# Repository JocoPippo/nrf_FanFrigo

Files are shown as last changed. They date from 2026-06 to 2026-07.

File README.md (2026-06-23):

# Introduzione
In estate il frigo trivalente soffre molto a causa delle alte temperature che non consentono un scambio termico adeguato della serpentina di raffreddamente.
In commercio esistono soluzioni ma queste sono pienamente soddisfacenti.
Così ho deciso di realizzare una soluzione che permetesse di:
- regolare la velocità delle ventole in base alla temperature del vano;
- monitorare e controllare da remoto lo stato della board;
- la seconda ventola, sen non forzata da applicativo, viene attivata quando la prima supera la soglia del 70% di utilizzo così da ridurre la rumorosità;
- non pesare sui consumi elettrici quando non necessario.

La cartella "pheripheral_frigo" contiene il progetto per "Visual studio Code" del firmware della board di gestione delle ventole.
La cartella hardware contiene il progetto in Kicad 9 e i file gerber della scheda di controllo.
"AndroidApp" contiene l'applicativo Android di gestione della board.
Ci si riferisca al file README.md interno a ciascuna cartella per dettagli specifici.

# BOARD
Attualmente la revisione del pcb è la 2.0 in cui è stato aggiunto il supporto per il sensore tachimetrico per ciascuna ventola e la possibilità di valutare la tensione della batteria. Al fine di mantenere i consumi bassi si è scelto di inserire il partitore di tensione sotto il mosfet di controllo della ventola1. Questa scelta, benchè renda più semplice il pcb, complica la parte software che è ancora in fase di sviluppo. Probabilmente verrà sostituta aggiungendo un ulteriore switch.
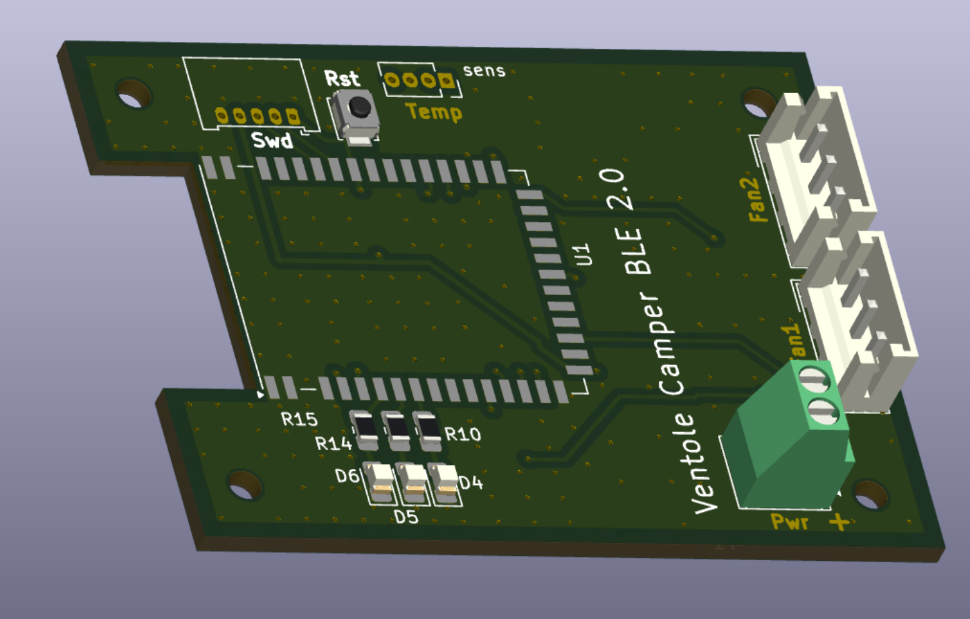
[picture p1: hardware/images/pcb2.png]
Vista lato superiore Front


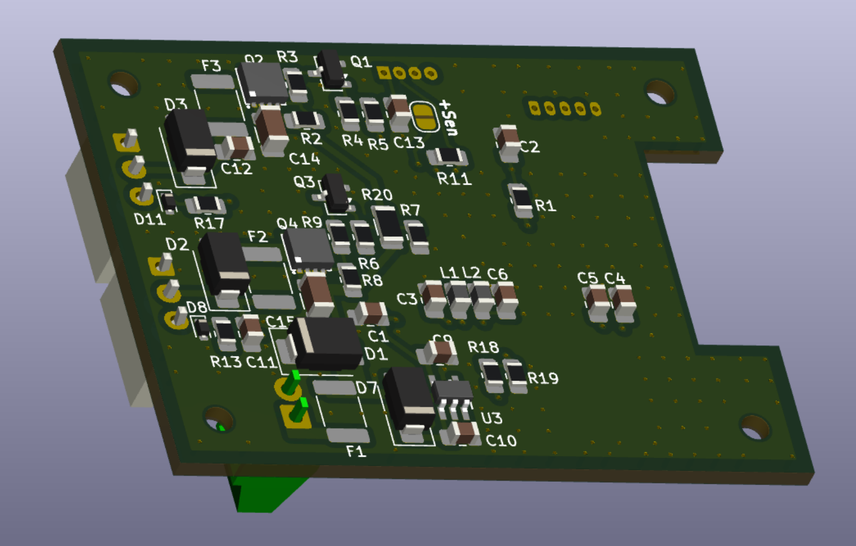
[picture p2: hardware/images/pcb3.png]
Vista lato inferiore BacK


# SOFTWARE GESTIONE
Basato sull'esempio "NRF Blinky" della nordic semiconductor è stato customizzato aggiungendo le funzionalità di riservatezza e di gestione della board.

La [pagina di gestione](AndroidApp/images/app1.png) consente di vedere lo stato corrente ed, eventualmente, di forzarlo. 
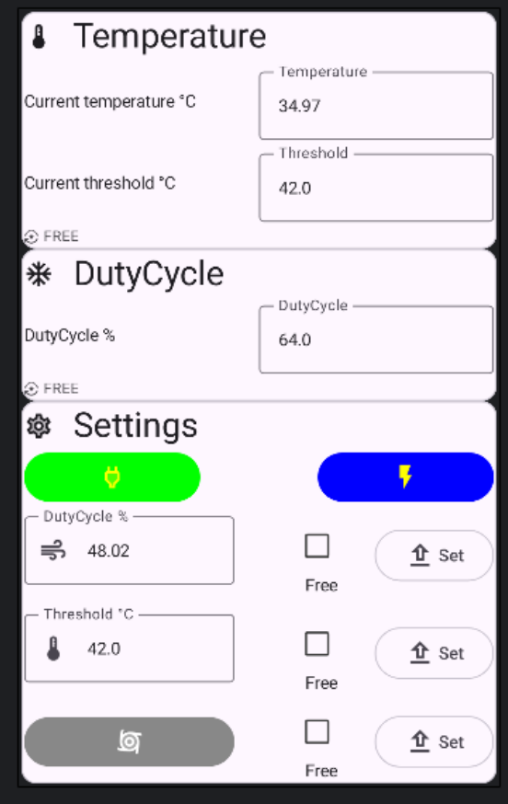
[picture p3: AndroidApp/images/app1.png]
pagina di gestione Board Status


Nella [pagina di settings](AndroidApp/images/App2.png ) si può cambiare la password che avrà valore transitorio fino al nuovo reset della scheda o tramite il ciclo power-off -> power-on o attraverso la pressione del tasto di reset. 
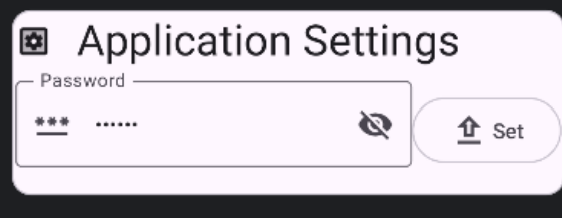
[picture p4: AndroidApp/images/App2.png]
pagina di settings App Settings


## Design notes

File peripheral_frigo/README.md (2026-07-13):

# Introduzione
In estate il frigo trivalente soffre molto a causa delle alte temperature che non consentono un scambio termico adeguato della serpentina di raffreddamente.
In commercio esistono soluzioni ma queste sono pienamente soddisfacenti.
Così ho deciso di realizzare una soluzione che permetesse di:
- regolare la velocità delle ventole in base alla temperature del vano;
- monitorare e controllare da remoto lo stato della board;
- la seconda ventola, sen non forzata da applicativo, viene attivata quando la prima supera la soglia del 70% di utilizzo così da ridurre la rumorosità;
- non pesare sui consumi elettrici quando non necessario.

La definizione dell'hardware la potete trovare qui: [hardware](../hardware/Ventole_Nrf52/). Utilizza una board custom, un sensore di temperatura DS18B20 e due ventole da 120x120mm (ma possono essere sostituite in base alla dimensione dello spazio utile a vostra disposizione).

L'applicazione di gestione su android la potete trovare qui: [AndroidApp](../AndroidApp/README.md). Basata sulla demo [Nrf BLINKY](https://github.com/nordicsemi/Android-nRF-Blinky) della nordic semiconductor è stata customizzata per il controllo e gestione della board custom. 

# Dettagli
Il firmware per la [board](https://github.com/JocoPippo/nrf_FanFrigo) si basa sul modulo [E73-2G4M04S1B](https://www.cdebyte.com/products/E73-2G4M04S1B/2) che utilizza il chip nfr52832 della nordic semiconductor, un ultra low power BLE soc che consente di controllare le ventole da remoto e, se in stand by mode consuma solo 3.5uA e circa 70uA in normal mode senza attivazione delle ventole.
Il che non rappresenta un problema per la batteria nei periodi di fermo prolungato del nostro mezzo.

# Setup
Il codice è scritto seguendo le linee guida del produttore qui troverete la descrizione per il [setup ambiente](https://academy.nordicsemi.com/courses/nrf-connect-sdk-fundamentals/lessons/lesson-1-nrf-connect-sdk-introduction/topic/exercise-1-1/). 
Allo stato della scrittura del codice le versioni dell'SDK e della toolchain è: 3.3.0.

Una volta importato il progetto dentro Visual Studio Code è necessario creare la configurazione di build selezionando "+Add build configuration" nella sezione "APPLICATIONS" di "NRF CONNECT".
- Nella sezione "Board Target" selezionare "Nordic SoC" e scegliere "ebyte_e73_tbb/nrf53832".
- Nella sezione "Base Devicetree Overlays" selezionare "boards/ebyte_e73_tbab_nrf52832.overlay"
- Nella sezione "Extra Devicetree Overlays" selezionare "arduino_serial.overlay"
A questo punto è possibile customizzare altre impostazione per uso specifico per il debugging o altro. Infine cliccare sul bottone "Generate and Build" per creare generare tutti le dipendenze e creare il file da flashare.

# Considerazioni
Attualmente il bluethooth è configurato con cifratura e password fissa definita nel codice, questo è stato necessario poichè non è presito alcun dispositivo di output per stampare la password di sessione.

L'appicativo di gestione consente il cambio dei parametri tra cui la temperatura di soglia e la password, che attualmente durano solo filno al ciclo di disconnessione dell'alimentazione. 
E' prevista la possibilità di salvare le impostazioni di sessione alliinterno della flash ma per il momento è stata commentata perchè salvare la password in modo definitivo avrebbe richiesto il re-flash in caso la si debba resettare.

# Sviluppi futuri 
Assieme alla prossima revisione hardware verranno aggiunte:
- la possibilità di monitorare la velocità delle ventole al fine di essere confidenti che non ci sia un impedimento meccanico alla rotazione;
- il monitoraggio della tesione della battaria durante l'azionamento della ventola principale.

# Creazione build per DFU/FOTA
Per poter eseguire l'aggiornamento via BLE NRF mette a disposizione un sistema automatico per creare il bootloader e integrare nell'applicativo la parte di gestione e scrittura del firmware. E' necessario creare una build che contenga il bootloader e le immagini per i due slot. 
Per rendere il sistema più sicuro è necessario generare una chiave per la firma che nel notro caso si dovrà chiamere _fan_private_2048.pem_ in quanto il makefile è configurato per questo nome file.
Di seguito i comandi da eseguire all'interno di un __"nRF terminal"__ (plugin "NRF CONNECT" -> sezione WELCOME -> Open terminal) per creare la prima immagine da flashare direttamente e il pacchetto __dfu_application.zip__ che contiene il firmware per l'aggiornamento.

### la generazione della chiave di cifratura
_openssl genrsa -out fan_private_2048.pem 2048_

### la build
entrare nella cartella del progetto _peripheral_frigo_ (cd <prj_path>/nrf_FanFrigo/peripheral_frigo)

_west build [-p] -b ebyte_e73_tbb/nrf52832 -- -DSB_CONFIG_BOOTLOADER_MCUBOOT=y ~~-DSB_CONFIG_MCUBOOT_MODE_DIRECT_XIP=y~~ -DCONFIG_NCS_SAMPLE_MCUMGR_BT_OTA_DFU=y -DDTC_OVERLAY_FILE=" <prj_path>/nrf_FanFrigo/peripheral_frigo/boards/ebyte_e73_tbab_nrf52832.overlay" -DDTC_EXTRA_OVERLAY_FILE=" <prj_path>/nrf_FanFrigo/peripheral_frigo/arduino_serial.overlay"_

L'opzione [-p] p è da usare per una _"pristine build"_, quindi la prima volta o quando si cambia la configurazione.
La modalità _SB_CONFIG_MCUBOOT_MODE_DIRECT_XIP_ non sembra funzionare correttamente durante l'aggiornamento, per ora è stata rimossa fino a quando non verrà scoprirta la causa.
Il segnaposto <prj_path> deve essere sostituito con il percorsco completo dove è presente il progetto _"nrf_FanFrigo"_

### il flash completo
 _west flash_   

## DFU
Per il caricamento del firmware può essere utilizzata l'applicazione __"nRF Connect"__ o, in alternativa, __"Device Manager"__. Una volta associato il dispositivo basta inviare il file et voilà l'aggiornamento è servito.

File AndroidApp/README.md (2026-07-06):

# INTRODUZIONE
Applicazione basata sull'esempio "nRF BLINKY" di nordic semiconductor è stato customizzato ed ampliato per adattarsi all'esigenza specifica.
Essendo la mia prima applicazione android, scusatemi per la presenza di errori ed alcuni piccoli e bug ma almeno fà ci per cui è destinata: controllare e comandare la board da remoto al fine di avere una gestione più corretta delle ventole e della temperatura.

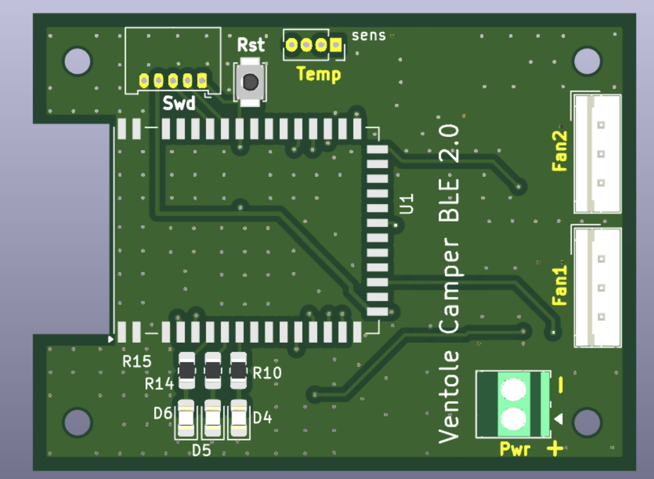
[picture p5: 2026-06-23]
hardware/images/pcb1.png

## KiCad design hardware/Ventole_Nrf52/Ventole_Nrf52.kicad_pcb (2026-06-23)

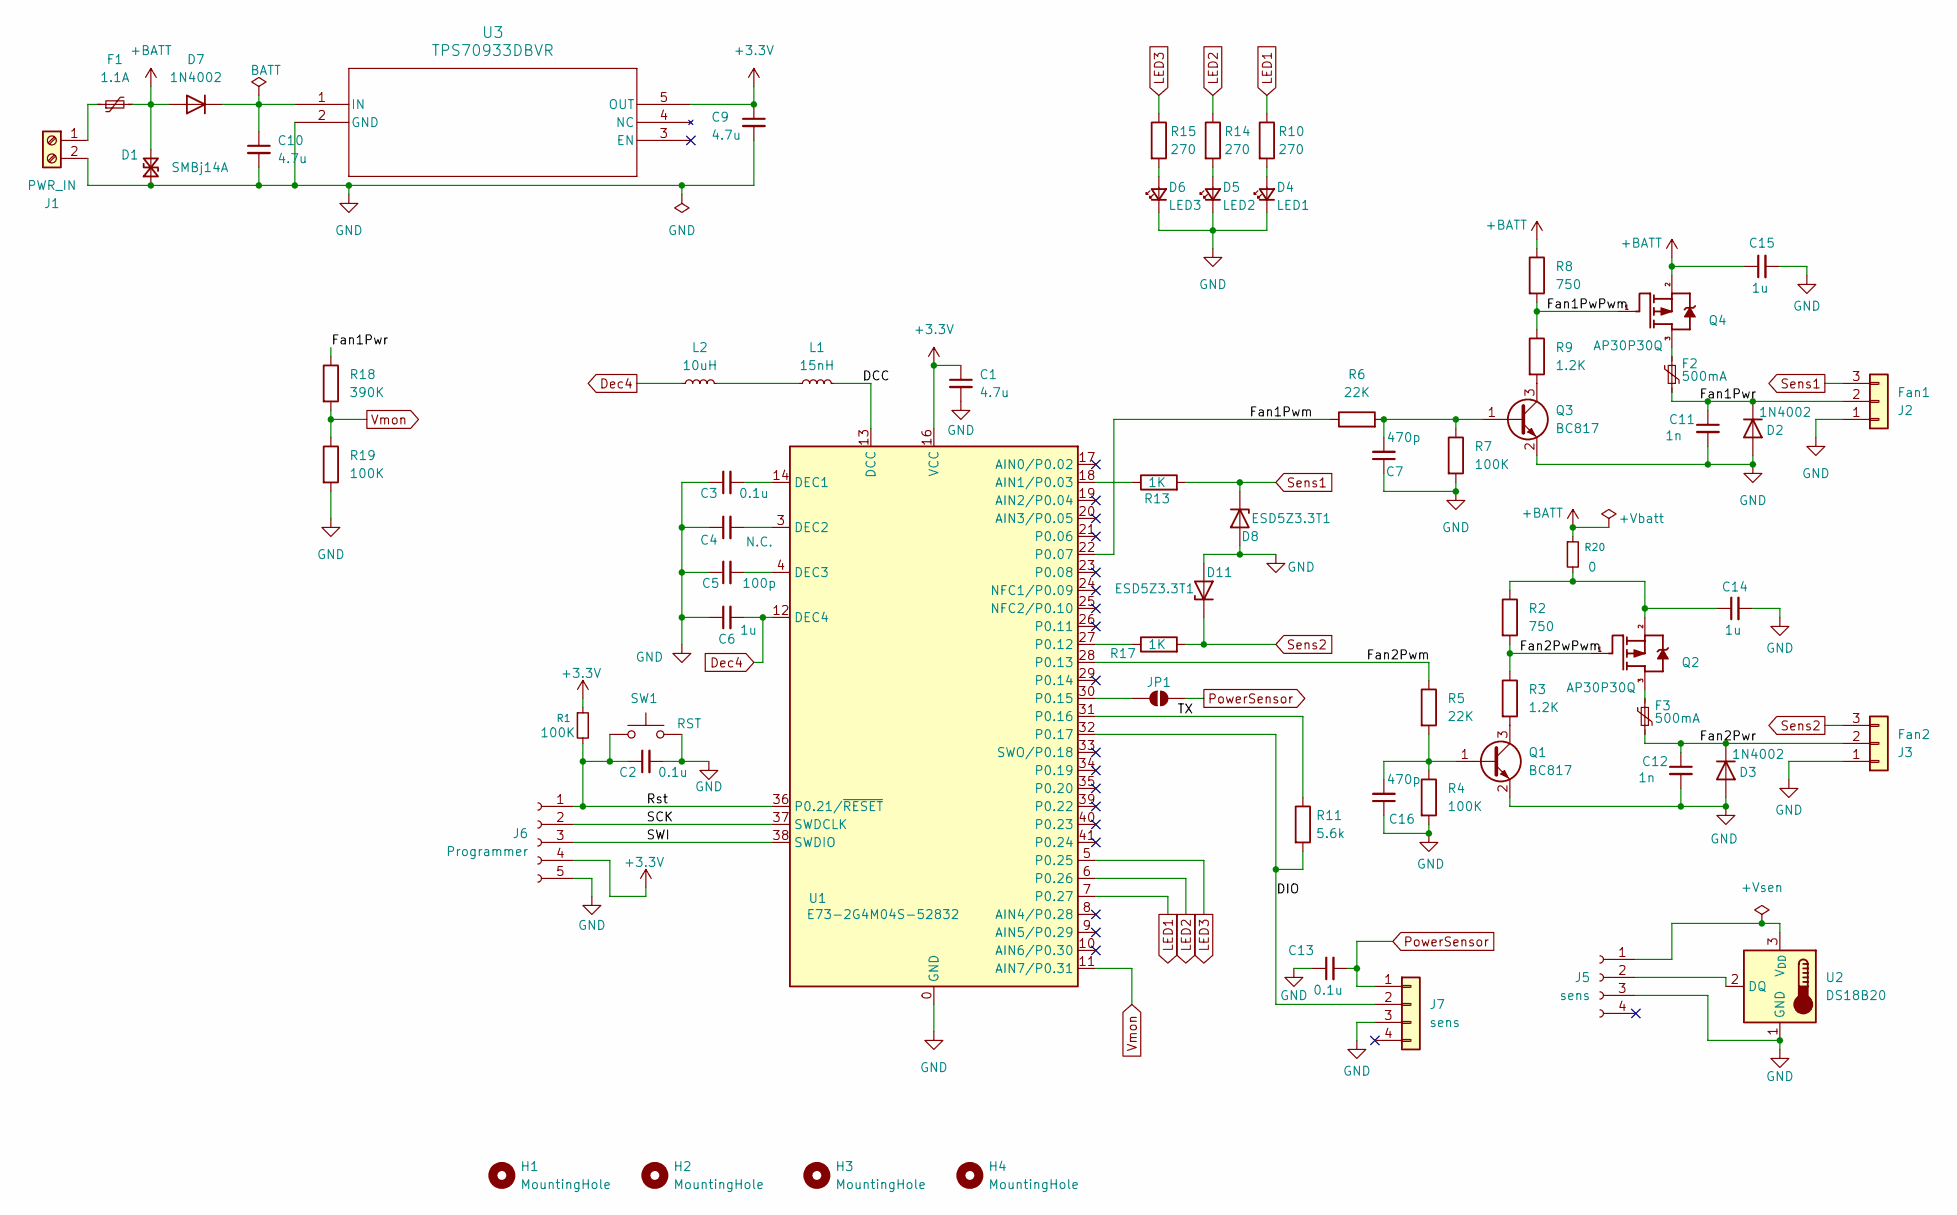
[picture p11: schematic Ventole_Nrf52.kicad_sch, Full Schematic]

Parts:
C1, C9, C10: 4.7u; C_0805_2012Metric_Pad1.18x1.45mm_HandSolder
C2, C3, C13: 0.1u; C_0805_2012Metric_Pad1.18x1.45mm_HandSolder
C4: N.C.; C_0805_2012Metric_Pad1.18x1.45mm_HandSolder
C5: 100p; C_0805_2012Metric_Pad1.18x1.45mm_HandSolder
C6: 1u; C_0805_2012Metric_Pad1.18x1.45mm_HandSolder
C7, C16: 470p; C_1206_3216Metric
C11, C12: 1n; C_0805_2012Metric_Pad1.18x1.45mm_HandSolder
C14, C15: 1u; C_1206_3216Metric
D1: SMBj14A; D_SMB
D2, D3, D7: 1N4002; D_SMA
D4: LED1; LED_0805_2012Metric_Pad1.15x1.40mm_HandSolder
D5: LED2; LED_0805_2012Metric_Pad1.15x1.40mm_HandSolder
D6: LED3; LED_0805_2012Metric_Pad1.15x1.40mm_HandSolder
D8, D11: ESD5Z3.3T1; D_SOD-523
F1: 1.1A; Fuse_1812_4532Metric_Pad1.30x3.40mm_HandSolder
F2, F3: 500mA; Fuse_1812_4532Metric_Pad1.30x3.40mm_HandSolder
H1, H2, H3, H4: MountingHole; MountingHole_2.2mm_M2
J1: PWR_IN; TerminalBlock_MX128-2-2.54_1x02_P2.54mm_Horizontal
J2: Fan1; JST_EH_B3B-EH-A_1x03_P2.50mm_Vertical
J3: Fan2; JST_EH_B3B-EH-A_1x03_P2.50mm_Vertical
J5: sens
J6: Programmer; Molex_PicoBlade_53048-0510_1x05_P1.25mm_Horizontal
J7: sens; PinSocket_1x04_P1.27mm_Vertical
JP1: PowerSensor; SolderJumper-2_P1.3mm_Open_RoundedPad1.0x1.5mm
L1: 15nH; L_0805_2012Metric_Pad1.05x1.20mm_HandSolder
L2: 10uH; L_0805_2012Metric_Pad1.05x1.20mm_HandSolder
Q1, Q3: BC817; SOT-23
Q2, Q4: AP30P30Q; DFN-8_3.0x3.0-E0.65_mos
R1, R4, R7, R19: 100K; R_0805_2012Metric_Pad1.20x1.40mm_HandSolder
R2, R8: 750; R_0805_2012Metric_Pad1.20x1.40mm_HandSolder
R3, R9: 1.2K; R_0805_2012Metric_Pad1.20x1.40mm_HandSolder
R5, R6: 22K; R_0805_2012Metric_Pad1.20x1.40mm_HandSolder
R10, R14, R15: 270; R_0805_2012Metric_Pad1.20x1.40mm_HandSolder
R11: 5.6k; R_0805_2012Metric_Pad1.20x1.40mm_HandSolder
R13, R17: 1K; R_0805_2012Metric_Pad1.20x1.40mm_HandSolder
R18: 390K; R_0805_2012Metric_Pad1.20x1.40mm_HandSolder
R20: 0; R_1206_3216Metric
SW1: RST; SW_SPST_B3U-1000P
U1: E73-2G4M04S-52832; E73-2G4M04S
U2: DS18B20; TO-92_Inline
U3: TPS70933DBVR; DBV5_TEX-M

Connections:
+3.3V: C1.1, C9.1, J6.4, R1.1, U1.16 (VCC), U3.5 (OUT)
+BATT: C15.1, D1.2 (A2), D7.2 (A), F1.2, Q4.2 (S), R8.1, R20.1
/DCC: L1.2, U1.13 (DCC)
/DIO: J7.2, R11.2, U1.32 (P0.17)
/Fan1PwPwm: Q4.1 (G), R8.2, R9.1
/Fan1Pwm: R6.1, U1.22 (P0.07)
/Fan1Pwr: C11.1, D2.1 (K), F2.1, J2.2, R18.1
/Fan2PwPwm: Q2.1 (G), R2.2, R3.1
/Fan2Pwm: R5.1, U1.28 (P0.13)
/Fan2Pwr: C12.1, D3.1 (K), F3.1, J3.2
/Rst: C2.1, J6.1, R1.2, SW1.1, U1.36 (P0.21/~RESET)
/SCK: J6.2, U1.37 (SWDCLK)
/SWI: J6.3, U1.38 (SWDIO)
/TX: R11.1, U1.31 (P0.16)
Dec4: C6.2, L2.1, U1.12 (DEC4)
GND: C1.2, C2.2, C3.1, C4.1, C5.1, C6.1, C7.1, C9.2, C10.2, C11.2, C12.2, C13.1, C14.2, C15.2, C16.1, D1.1 (A1), D2.2 (A), D3.2 (A), D4.1 (K), D5.1 (K), D6.1 (K), D8.2 (A), D11.2 (A), J1.2, J2.1, J3.1, J5.3, J6.5, J7.3, Q1.2 (E), Q3.2 (E), R4.2, R7.2, R19.2, SW1.2, U1.0 (GND), U1.1 (GND), U1.2 (GND), U1.15 (GND), U1.42 (GND), U1.43 (GND), U2.1 (GND), U3.2 (GND)
LED1: R10.1, U1.7 (P0.27)
LED2: R14.1, U1.6 (P0.26)
LED3: R15.1, U1.5 (P0.25)
unnamed: D4.2 (A), R10.2
unnamed: D5.2 (A), R14.2
unnamed: D6.2 (A), R15.2
unnamed: C10.1, D7.1 (K), U3.1 (IN)
unnamed: F1.1, J1.1
unnamed: J5.1, U2.3 (V_{DD})
unnamed: J5.2, U2.2 (DQ)
unnamed: JP1.1 (A), U1.30 (P0.15)
unnamed: L1.1, L2.2
unnamed: C16.2, Q1.1 (B), R4.1, R5.2
unnamed: Q1.3 (C), R3.2
unnamed: F3.2, Q2.3 (D)
unnamed: C14.1, Q2.2 (S), R2.1, R20.2
unnamed: C7.2, Q3.1 (B), R6.2, R7.1
unnamed: Q3.3 (C), R9.2
unnamed: F2.2, Q4.3 (D)
unnamed: R13.1, U1.18 (AIN1/P0.03)
unnamed: C3.2, U1.14 (DEC1)
unnamed: C4.2, U1.3 (DEC2)
unnamed: C5.2, U1.4 (DEC3)
unnamed: R17.1, U1.27 (P0.12)
PowerSensor: C13.2, J7.1, JP1.2 (B)
Sens1: D8.1 (K), J2.3, R13.2
Sens2: D11.1 (K), J3.3, R17.2
Vmon: R18.2, R19.1, U1.11 (AIN7/P0.31)

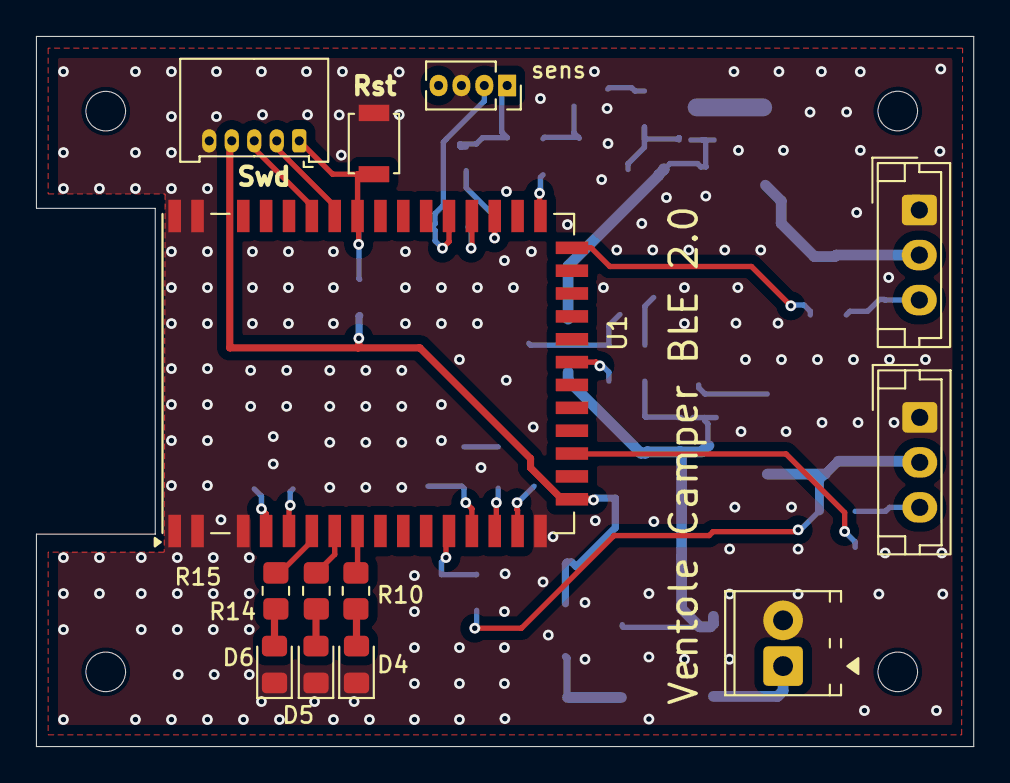
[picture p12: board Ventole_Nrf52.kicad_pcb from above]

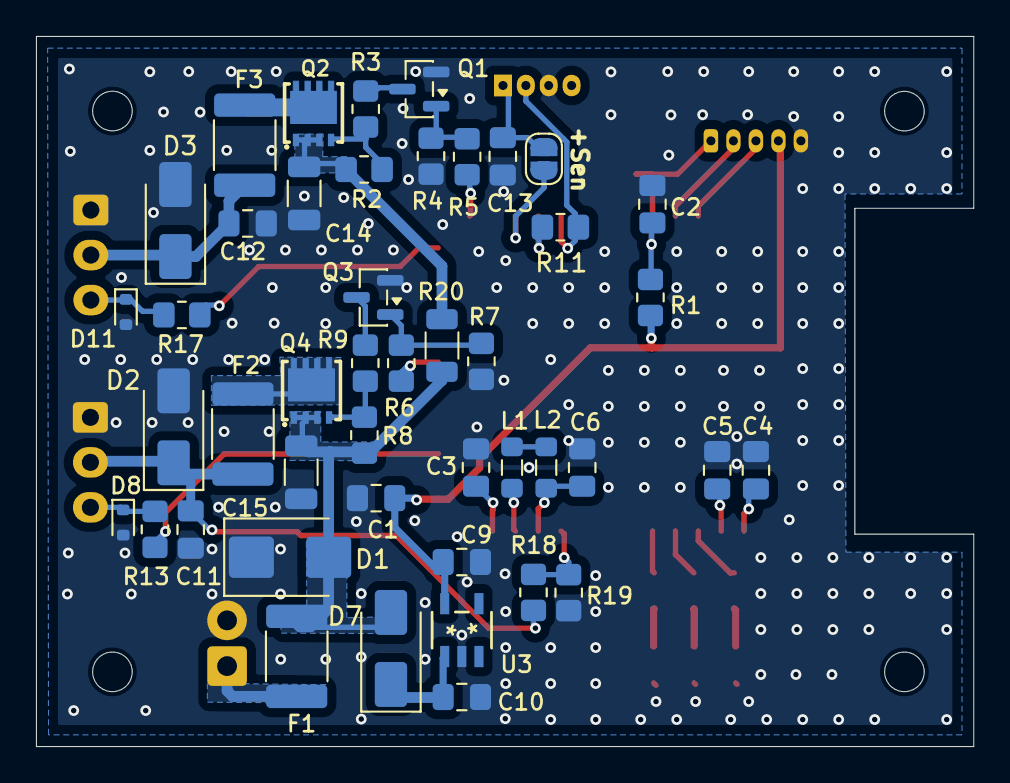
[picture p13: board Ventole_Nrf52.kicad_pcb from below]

Board: 2 copper layers, 52.1 x 39.5 mm, 62 parts (45 on the bottom side), 42 nets.

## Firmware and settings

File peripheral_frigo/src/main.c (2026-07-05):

/*
 * Copyright (c) 2023 Nordic Semiconductor ASA
 *
 * SPDX-License-Identifier: LicenseRef-Nordic-5-Clause
 */

#include <zephyr/kernel.h>
#include <zephyr/logging/log.h>
#include <zephyr/bluetooth/gap.h>
#include <zephyr/bluetooth/uuid.h>
#include <zephyr/bluetooth/conn.h>
#include <zephyr/posix/netinet/in.h>
#include <zephyr/drivers/gpio.h>
#include <zephyr/drivers/sensor.h>
#include <zephyr/drivers/pwm.h>
#include <zephyr/bluetooth/bluetooth.h>
#include <zephyr/pm/device.h>

#include <zephyr/net/net_ip.h>
#include <zephyr/posix/arpa/inet.h>

#include <zephyr/bluetooth/hci_vs.h>
#include <zephyr/settings/settings.h>

//#include <zephyr/settings/settings.h> // for bonding and flash access
#include "my_fbs.h"

LOG_MODULE_REGISTER(Fan_Frigo_Camper, 1);

#define DEVICE_NAME CONFIG_BT_DEVICE_NAME
#define DEVICE_NAME_LEN (sizeof(DEVICE_NAME) - 1)

#define RUN_STATUS_LED DK_LED1
#define CON_STATUS_LED DK_LED2

#define STACKSIZE 1024
#define PRIORITY 7

#define RUN_LED_BLINK_INTERVAL 2000

#define MAX_PULSE_NS 50000
#define MAX_PULSE_2FAN2 30000
//#define MAX_PULSE_2FAN2 20000
#define MIN_PULSE_WIDTH	7500
//#define MIN_PULSE_WIDTH	250

#define GETMASK(size)  ((1ULL<<(((size)*8)-1))-1)

#define INT2FLOAT_BITS 16
#define HI_INT2FLOAT_MASK  0xFFFF0000U
#define LOW_INT2FLOAT_MASK 0x0000FFFFU

#define MAX_TEMPERATURE 80U

#define STORAGE_SETTINGS_ROOT "up"
#define STORAGE_SETTINGS_KEY  "key"
#define STORAGE_SETTINGS_TEMP  "temp"


struct stateAndValueU32 {
 uint32_t value;
 bool forced;
};

struct stateAndValueBool {
 bool value;
 bool forced;
};

static int fan_settings_set(const char *name, size_t len,
                            settings_read_cb read_cb, void *cb_arg);
static int fan_settings_export(int (*storage_func)(const char *name, const void *value, size_t val_len));
struct settings_handler fan_conf = {
    .name = STORAGE_SETTINGS_ROOT,
    .h_set = fan_settings_set,
    .h_export = fan_settings_export
};

/* Define the data you want to stream over Bluetooth LE */
// stores the used dutycycle 
static uint32_t local_dutycycle_value = 0;
// stores the remote required dutycycle
static struct stateAndValueU32 app_dutycycle = {0,false};
static bool local_fan2State = false;
static struct stateAndValueBool app_fan2State = {false,false};
static bool app_poweron_state = true;
static uint32_t app_temperature_value = 10<<INT2FLOAT_BITS;
static struct stateAndValueU32 app_threshold ={32<<INT2FLOAT_BITS, false};// = 42<<INT2FLOAT_BITS;
static bool app_leds_state = true;
static bool connection_state = false;
static bool pwmOff = false;
static uint32_t dutyPulse;


static const struct gpio_dt_spec fanGpio_spec = GPIO_DT_SPEC_GET(DT_ALIAS(fan2), gpios);
static const struct gpio_dt_spec powerGpio_spec = GPIO_DT_SPEC_GET(DT_ALIAS(poweron), gpios);
static const struct pwm_dt_spec pwm_fan1 = PWM_DT_SPEC_GET(DT_NODELABEL(fanpwm1));
static const struct pwm_dt_spec pwm_fan2 = PWM_DT_SPEC_GET(DT_NODELABEL(fanpwm2));


static const struct gpio_dt_spec led0_spec = GPIO_DT_SPEC_GET(DT_ALIAS(led0), gpios);
static const struct gpio_dt_spec led1_spec = GPIO_DT_SPEC_GET(DT_ALIAS(led1), gpios);
static const struct gpio_dt_spec led2_spec = GPIO_DT_SPEC_GET(DT_NODELABEL(led2), gpios);

static const struct  device *uart_dev = DEVICE_DT_GET(DT_NODELABEL(uart0));

static const struct gpio_dt_spec btn0_spec = GPIO_DT_SPEC_GET(DT_NODELABEL(button0), gpios);
static const struct gpio_dt_spec btn1_spec = GPIO_DT_SPEC_GET(DT_NODELABEL(button1), gpios);

static const struct bt_data ad[] = {
	BT_DATA_BYTES(BT_DATA_FLAGS, (BT_LE_AD_GENERAL | BT_LE_AD_NO_BREDR)),
	BT_DATA(BT_DATA_NAME_COMPLETE, DEVICE_NAME, DEVICE_NAME_LEN),

};

static const struct bt_le_adv_param *adv_param = BT_LE_ADV_PARAM(
	(BT_LE_ADV_OPT_CONN | BT_LE_ADV_OPT_USE_IDENTITY), /* Connectable advertising and use identity address */
	3400, /* Min Advertising Interval 3000ms (4800*0.625ms) */
	4200, /* Max Advertising Interval 3375ms (5400*0.625ms) */
	NULL); /* Set to NULL for undirected advertising */

static struct k_work adv_work;


static const struct bt_data sd[] = {
	BT_DATA_BYTES(BT_DATA_UUID128_ALL, BT_UUID_FBS_VAL),
};

struct k_sem dutycycle_sem;
bool dutyToBeUpdate = false;

// for FAN2 managements
bool fan2ToBeUpdate = false;
static bool fan2ToBeStarted;

const struct device *tempDev;
unsigned int passkey = 123456;

float getFloatTemp4Int(uint32_t T_Arg);
static void app_setLeds_cb(bool ledState);

static void advertising_start(void)
{
	k_work_submit(&adv_work);
}

static void adv_work_handler(struct k_work *work)
{
	int err = bt_le_adv_start(adv_param, ad, ARRAY_SIZE(ad), sd, ARRAY_SIZE(sd));

	if (err) {
		LOG_DBG("Advertising failed to start (err %d)\n", err);
		return;
	}

	LOG_DBG("Advertising successfully started\n");
}

static void display_passkey(struct bt_conn *conn, unsigned int passkey)
{
	char peer_addr[BT_ADDR_LE_STR_LEN];
	bt_addr_le_to_str(bt_conn_get_dst(conn), peer_addr, sizeof(peer_addr));

	LOG_INF("Enter passkey on %s: %06u", peer_addr, passkey);
}

static void cancel_authentication(struct bt_conn *conn)
{
	char peer_addr[BT_ADDR_LE_STR_LEN];
	bt_addr_le_to_str(bt_conn_get_dst(conn), peer_addr, sizeof(peer_addr));

	LOG_INF("Pairing canceled by remote: %s", peer_addr);
}

/*
 * Get a device structure from a devicetree node with compatible
 * "maxim,ds18b20". (If there are multiple, just pick one.)
 */

static const struct device *get_ds18b20_device(void)
{
	const struct device *const dev = DEVICE_DT_GET_ANY(maxim_ds18b20);

	if (dev == NULL) {
		// No such node, or the node does not have status "okay". //
		LOG_DBG("\nError: no device found.\n");
		return NULL;
	}

	if (!device_is_ready(dev)) {
		LOG_DBG("\nError: Device \"%s\" is not ready; "
		       "check the driver initialization logs for errors.\n",
		       dev->name);
		return NULL;
	}

	LOG_DBG("Found device \"%s\", getting sensor data\n", dev->name);
	return dev;
}

/*
static void pairing_confirm(struct bt_conn *conn)
{
	char addr[BT_ADDR_LE_STR_LEN];

	bt_addr_le_to_str(bt_conn_get_dst(conn), addr, sizeof(addr));

	bt_conn_auth_pairing_confirm(conn);

	LOG_DBG("Pairing confirmed: %s\n", addr);
}

static void pairing_complete(struct bt_conn *conn, bool bonded)
{
	char addr[BT_ADDR_LE_STR_LEN];

	bt_addr_le_to_str(bt_conn_get_dst(conn), addr, sizeof(addr));

	LOG_DBG("Pairing completed: %s, bonded: %d\n", addr, bonded);
}

static void pairing_failed(struct bt_conn *conn, enum bt_security_err reason)
{
	char addr[BT_ADDR_LE_STR_LEN];

	bt_addr_le_to_str(bt_conn_get_dst(conn), addr, sizeof(addr));

	LOG_DBG("Pairing failed conn: %s, reason %d\n", addr, reason);
}
*/

static uint32_t uintFromFloat(float data) {
	uint32_t result;

	result = (uint32_t) data;
	data -= result;
	result <<= INT2FLOAT_BITS;
	return result | (int32_t)(data *100.f);
}

static uint32_t pulse2Uint(uint32_t pulse) {

	uint32_t result;
	float tmp;
	tmp = ((float)pulse/(float)MAX_PULSE_NS)* 100.0f;
	result = uintFromFloat(tmp);
	return result;
}

static uint32_t percentage2Uint(uint32_t percentage) {

	uint32_t result;
	float tmp = getFloatTemp4Int(percentage); // percentage in float rappresentation
	if(tmp > ((float)MAX_PULSE_2FAN2/((float)MAX_PULSE_NS)*100.0f))
		tmp *=2;	
	result = (tmp * (float)MAX_PULSE_NS/100.0f);
	return result;
}


static void recycled_cb(void)
{
	LOG_DBG("Connection object available from previous conn. Disconnect is complete!\n");
	advertising_start();
}

static uint32_t app_getDutyCycle_cb(void)
{
	uint32_t result;
	if(app_dutycycle.forced) {
		result = pulse2Uint(app_dutycycle.value);
		result |= app_dutycycle.forced<<(sizeof(app_dutycycle.value)*8-1);
	}
	else {
		result = pulse2Uint(local_dutycycle_value);
	}
	return result;
}

static uint8_t app_getFan2_cb(void)
{
	if(app_fan2State.forced)
		return app_fan2State.value | app_fan2State.forced<<(sizeof(app_fan2State.value)*8-1);
	else
		return local_fan2State;

}

static bool app_getPoweron_cb(void)
{
	return app_poweron_state;
}

static int32_t app_getTemperature_cb(void)
{
	return app_temperature_value;
}

static uint32_t app_getThreshold_cb(void)
{
	uint32_t result;
	result = app_threshold.value;
	if(app_threshold.forced) {
		result |= app_threshold.forced<<(sizeof(app_threshold.value)*8-1);
	}
	return result;
}

static bool app_getLeds_cb(void)
{
	return app_leds_state;
}

/**
 * callback used to set the dutycycle value
 * @param dutyCycleValue represents the new value of dutycycle to set
 * 					a negative value indicates the value has to be forced
 * 					a postive value indicates to use the calculated value
 */
static void app_setDutyCycle_cb(uint32_t dutyCycleValue)
{
	dutyCycleValue = htonl(dutyCycleValue); 

	if(dutyCycleValue & 0x80000000U) {
		app_dutycycle.forced = true;
			//LPP due the received value is set as percentage of pulse it must be re-calibrate in 
		// order to obtain the pulse period
		app_dutycycle.value = percentage2Uint(GETMASK(sizeof(app_dutycycle.value)) & dutyCycleValue);
		app_dutycycle.value = app_dutycycle.value>MAX_PULSE_NS?MAX_PULSE_NS:app_dutycycle.value;
		app_dutycycle.value = app_dutycycle.value<MIN_PULSE_WIDTH?0:app_dutycycle.value;

	}
	else {
		app_dutycycle.forced = false;
		app_dutycycle.value = local_dutycycle_value;
/* 		{
			k_sem_take(&dutycycle_sem, K_FOREVER);
			fan2ToBeUpdate=true;
			k_sem_give(&dutycycle_sem);
		} */
	}

	k_sem_take(&dutycycle_sem, K_FOREVER);
	dutyToBeUpdate = true;
	k_sem_give(&dutycycle_sem);
}

/**
 * callback used to set the Fan2 state
 * @param fan2_state indicates if the Fan2 must be set or not
 * 					a negative value indicates the state has to be forced
 * 					a postive value indicates to use the automatic (calculated) state
 */
static void app_setFan2_cb(uint8_t fan2_state)
{
	int size = sizeof(app_fan2State.value);
	//LPP TODO VERIFY HOW HANDLE THE IO in case on not forced -> shall be the stored previous state???
	if(fan2_state & (1<<(size*8-1))) {
		app_fan2State.forced = true;
		fan2_state &= GETMASK(size);
		app_fan2State.value = fan2_state; // evaluate the action
	}
	else {
		app_fan2State.forced = false;
		//status and pwm counter will be set in the next iteration of temperature acquisition
	}

/* 	k_sem_take(&fan_sem, K_FOREVER);
	fan2ToBeUpdate=true;
	k_sem_give(&fan_sem);
 */
	k_sem_take(&dutycycle_sem, K_FOREVER);
	fan2ToBeUpdate=true;
	dutyToBeUpdate = true;
	k_sem_give(&dutycycle_sem);
}


/**
 * The function `set_tx_power` is used to set the transmit power level for a specific Bluetooth handle.
 * 
 * @param handle_type The `handle_type` parameter in the `set_tx_power` function is used to specify the
 * type of handle being used. It is of type `uint8_t` and is passed as an argument to the function. The
 * handle type typically indicates whether the handle refers to a connection handle, advertising handle
 * @param handle The `handle` parameter in the `set_tx_power` function is used to specify the
 * connection handle for which the transmit power level needs to be set. It is of type `uint16_t`,
 * which means it is a 16-bit unsigned integer value. This handle uniquely identifies the connection
 * between the
 * @param tx_pwr_lvl The `tx_pwr_lvl` parameter in the `set_tx_power` function represents the transmit
 * power level that you want to set for a specific Bluetooth device. It is of type `int8_t`, which
 * means it is an 8-bit signed integer representing the power level in decibels (
 * 
 * @return The function `set_tx_power` returns void, which means it does not return any value.
 */
static void set_tx_power(uint8_t handle_type, uint16_t handle, int8_t tx_pwr_lvl)
{
	struct bt_hci_cp_vs_write_tx_power_level *cp;
	struct bt_hci_rp_vs_write_tx_power_level *rp;
	struct net_buf *buf, *rsp = NULL;
	int err;
	buf = bt_hci_cmd_alloc(K_TIMEOUT_ABS_MS(1)); 
	//buf = bt_hci_cmd_create(BT_HCI_OP_VS_WRITE_TX_POWER_LEVEL,
	//			sizeof(*cp));
	if (!buf) {
		printk("Unable to allocate command buffer\n");
		return;
	}

	cp = net_buf_add(buf, sizeof(*cp));
	cp->handle = sys_cpu_to_le16(handle);
	cp->handle_type = handle_type;
	cp->tx_power_level = tx_pwr_lvl;

	err = bt_hci_cmd_send_sync(BT_HCI_OP_VS_WRITE_TX_POWER_LEVEL,
				   buf, &rsp);
	if (err) {
		uint8_t reason = rsp ?
			((struct bt_hci_rp_vs_write_tx_power_level *)
			  rsp->data)->status : 0;
		printk("Set Tx power err: %d reason 0x%02x\n", err, reason);
		return;
	}

	rp = (void *)rsp->data;

	net_buf_unref(rsp);
}

/**
 * set Uart power state
 */
static void setUartPowerOnState(bool enabled) {
	int rc;
	if(!enabled) {
		rc = pm_device_action_run(uart_dev , PM_DEVICE_ACTION_SUSPEND);
		if (rc < 0) {
			LOG_ERR("Could not suspend uart0 (%d)\n" , rc);
		}
	}
	else {
		rc = pm_device_action_run(uart_dev , PM_DEVICE_ACTION_RESUME);
		if (rc < 0) {
			LOG_ERR("Could not resume uart0 (%d)\n" , rc);
		}
	}
}

/**
 * set leds and PWM power state
 */
static void setDeviceEnableState(bool enabled) {
	int rc;
	if(!enabled) {
		// turn off leds
		bool prevLedState = app_leds_state;
		app_setLeds_cb(false);
		app_leds_state = prevLedState;

		rc = pm_device_action_run(pwm_fan1.dev , PM_DEVICE_ACTION_SUSPEND);
		if (rc < 0) {
			LOG_ERR("Could not suspend fan1 (%d)\n" , rc);
		}
		rc = pm_device_action_run(pwm_fan2.dev , PM_DEVICE_ACTION_SUSPEND);
		if (rc < 0) {
			LOG_ERR("Could not suspend fan2 (%d)\n" , rc);
		}

	}
	else {
		//turn on leds
		if(app_leds_state)
			app_setLeds_cb(true);

		rc = pm_device_action_run(pwm_fan1.dev , PM_DEVICE_ACTION_RESUME);
		if (rc < 0) {
			LOG_ERR("Could not resume fan1 (%d)\n" , rc);
		}
		rc = pm_device_action_run(pwm_fan2.dev , PM_DEVICE_ACTION_RESUME);
		if (rc < 0) {
			LOG_ERR("Could not resume fan2 (%d)\n" , rc);
		}
		if(pwm_set_pulse_dt(&pwm_fan1, 0) !=0 ) {
    		LOG_ERR("Error: setting 0 pulse to device %s", pwm_fan1.dev->name);
		}
		if(pwm_set_pulse_dt(&pwm_fan2, 0) !=0 ) {
    		LOG_ERR("Error: setting 0 pulse to device %s", pwm_fan2.dev->name);
		}
	}
}



static void app_setPoweron_cb(bool poweron) {
 
	if (app_poweron_state && !poweron) {
		setUartPowerOnState(false);
		setDeviceEnableState(false);
		pwmOff = true;
	}
	if (!app_poweron_state && poweron) {
		setUartPowerOnState(true);
		setDeviceEnableState(true);
		// to avoid restart fan to maximum when powered off and on
		k_sem_take(&dutycycle_sem, K_NO_WAIT);
		//to upadate the dutycycle value
		dutyToBeUpdate = true;
		//and force the change 
		fan2ToBeUpdate=true;
		k_sem_give(&dutycycle_sem);		
		pwmOff = false;
	}
	app_poweron_state = poweron; // evaluate the action
}

static void app_setThreshold_cb(uint32_t thresholdValue)
{	
	thresholdValue = htonl(thresholdValue); 
	
	if(thresholdValue & 0x80000000U) {
		app_threshold.forced = true;
		app_threshold.value = GETMASK(sizeof(app_threshold.value)) & thresholdValue;
		uint32_t maxTmp= (MAX_TEMPERATURE << INT2FLOAT_BITS);
		app_threshold.value = app_threshold.value>maxTmp?maxTmp:app_threshold.value;
	}
	else {
		app_threshold.forced = false;
	}
}


static void app_setLeds_cb(bool ledState) {
int rc;
	if (app_leds_state && !ledState) {
		gpio_pin_configure_dt(&led0_spec , GPIO_INPUT | GPIO_PULL_DOWN);
		gpio_pin_configure_dt(&led1_spec , GPIO_INPUT | GPIO_PULL_DOWN);
		rc = pm_device_action_run(led0_spec.port , PM_DEVICE_ACTION_SUSPEND);
		if (rc < 0) { 
			LOG_ERR("Could not suspend led0 (%d)\n" , rc);
		}
		rc = pm_device_action_run(led1_spec.port , PM_DEVICE_ACTION_SUSPEND);
		if (rc < 0) {
			LOG_ERR("Could not suspend led1 (%d)\n" , rc);
		} 
	}
	if (!app_leds_state && ledState) {
 		rc = pm_device_action_run(led0_spec.port , PM_DEVICE_ACTION_RESUME);
		if (rc < 0) {
			LOG_ERR("Could not resume led0 (%d)\n" , rc);
		}
		rc = pm_device_action_run(led1_spec.port , PM_DEVICE_ACTION_RESUME);
		if (rc < 0) {
			LOG_ERR("Could not resume led1 (%d)\n" , rc);
		} 
		gpio_pin_configure_dt(&led0_spec , GPIO_OUTPUT_LOW);
		gpio_pin_configure_dt(&led1_spec , GPIO_OUTPUT_LOW);
		//if connected then lights up the led
		gpio_pin_set_dt(&led1_spec, connection_state);
	}

	app_leds_state = ledState; // evaluate the action
}


static void app_setPsw_cb(uint32_t pswValue)
{
	pswValue = htonl(pswValue); 

	passkey = pswValue;
	bt_passkey_set(passkey);
	//LPP TODO TODO
	//execute a disconnetion in order to use the new password
}

/* STEP 18.1 - Define the thread function  */
/*
void send_data_thread(void)
{
	while (1) {
		// Simulate data //
		simulate_data();
		// Send notification, the function sends notifications only if a client is subscribed //
		my_fbs_send_temperature_notify(app_temperature_value);
		k_sleep(K_MSEC(NOTIFY_INTERVAL));
	}
}
*/

/* STEP 18.1 - Define the thread function  */
/*
void send_duty_thread(void)
{
	while (1) {
		// Simulate data //
		simulate_dutycycle();
		// Send notification, the function sends notifications only if a client is subscribed //
		my_fbs_send_dutycycle_notify(app_dutycycle_value);
		k_sleep(K_MSEC(NOTIFY_INTERVAL));
	}
}
*/

static int init_pwm(void) {

	if (!pwm_is_ready_dt(&pwm_fan1)) {
    	LOG_ERR("Error: PWM device %s is not ready", pwm_fan1.dev->name);
    	return -1;
	}

	if (!pwm_is_ready_dt(&pwm_fan2)) {
    	LOG_ERR("Error: PWM device %s is not ready", pwm_fan2.dev->name);
    	return -1;
	}
	if(pwm_set_pulse_dt(&pwm_fan1, 0) !=0 ) {
    	LOG_ERR("Error: setting 0 pulse to device %s", pwm_fan1.dev->name);
    	return -1;
	}
	if(pwm_set_pulse_dt(&pwm_fan2, 0) !=0 ) {
    	LOG_ERR("Error: setting 0 pulse to device %s", pwm_fan2.dev->name);
    	return -1;
	}
	return 0;
}

static void on_connected(struct bt_conn *conn, uint8_t err)
{
	if (err) {
		LOG_DBG("Connection failed (err %u)\n", err);
		return;
	}

	LOG_DBG("Connected\n");
	gpio_pin_set_dt(&led1_spec, 1);
	connection_state=true;
}
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
int main(void)
{
	int blink_status = 0;
	int err;
	k_sem_init(&dutycycle_sem, 1, 1);

	LOG_INF("Starting acquiring temp sensor \n");
	tempDev = get_ds18b20_device();
	
	if (tempDev == NULL) {
		return 0;
	}
	
	gpio_pin_configure_dt(&led0_spec, GPIO_OUTPUT);
	gpio_pin_configure_dt(&led1_spec, GPIO_OUTPUT);
	gpio_pin_configure_dt(&led2_spec, GPIO_OUTPUT);
	gpio_pin_set_dt(&led0_spec, 0);
	gpio_pin_set_dt(&led1_spec, 0);
	gpio_pin_set_dt(&led2_spec, 0);

	
	err = init_pwm();
	if (err) {
		LOG_ERR("PWM init failed (err %d)\n", err);
		return -1;
	}
	
	err = bt_enable(NULL);
	if (err) {
		LOG_ERR("Bluetooth init failed (err %d)\n", err);
		return -1;
	}
	//UNUSED so configure as input to reduce power
	gpio_pin_configure_dt(&btn0_spec, GPIO_INPUT | GPIO_PULL_DOWN);
	gpio_pin_configure_dt(&btn1_spec, GPIO_INPUT | GPIO_PULL_DOWN);
	err = pm_device_action_run(btn0_spec.port, PM_DEVICE_ACTION_SUSPEND);
	if (err < 0) {
			LOG_ERR("Could not suspend button0 (%d)\n", err);
	}
	err = pm_device_action_run(btn1_spec.port, PM_DEVICE_ACTION_SUSPEND);
	if (err < 0) {
			LOG_ERR("Could not suspend button1 (%d)\n", err);
	}
	gpio_pin_configure_dt(&led2_spec, GPIO_INPUT | GPIO_PULL_DOWN);
	err = pm_device_action_run(led2_spec.port, PM_DEVICE_ACTION_SUSPEND);
	if (err < 0) {
			LOG_ERR("Could not suspend led2 (%d)\n", err);
	}
	// no more used
	gpio_pin_configure_dt(&fanGpio_spec , GPIO_INPUT | GPIO_PULL_DOWN);
	err = pm_device_action_run(fanGpio_spec.port, PM_DEVICE_ACTION_SUSPEND);
	if (err < 0) {
			LOG_ERR("Could not suspend fanGpio (%d)\n", err);
	}
	
	gpio_pin_configure_dt(&powerGpio_spec , GPIO_INPUT | GPIO_PULL_DOWN);
	err = pm_device_action_run(powerGpio_spec.port, PM_DEVICE_ACTION_SUSPEND);
	if (err < 0) {
			LOG_ERR("Could not suspend powerGpio (%d)\n", err);
	}
	app_setPoweron_cb(true);

	//LPP TO BE REVIEW
	//initialize and load settings from internal flash
	//fan_settings_init();
	//	settings_save_one(STORAGE_SETTINGS_ROOT"/"STORAGE_SETTINGS_KEY, &passkey, sizeof(passkey));
	//	settings_save_one(STORAGE_SETTINGS_ROOT"/"STORAGE_SETTINGS_TEMP, &(app_threshold.value), sizeof(app_threshold.value));
	

	// unsigned int passkey = 181181;
	bt_passkey_set(passkey);
	bt_conn_auth_cb_register(&auth_callbacks);
	//NRF_FICR->DEVICEID[0] ^ NRF_FICR->DEVICEID[1]
	//NRF_FICR->DEVICEADDR[0] ^ NRF_FICR->DEVICEADDR[1];
	
	bt_conn_cb_register(&connection_callbacks);

	err = my_fbs_init(&app_callbacks);
	if (err) {
		LOG_DBG("Failed to init LBS (err:%d)\n", err);
		return -1;
	}
	LOG_INF("Bluetooth initialized\n");
	k_work_init(&adv_work, adv_work_handler);
	advertising_start();

	app_setLeds_cb(false);
	setDeviceEnableState(false);
	pwmOff = true;
	fan2ToBeStarted=true;
	//set_tx_power(BT_HCI_VS_LL_HANDLE_TYPE_ADV, 0, -20);

	struct sensor_value temp;
	uint32_t tmpTemp=0;
	// take in account how long can be the sleep
	uint32_t counterLoop=1;

	for (;;) {

		while(!app_poweron_state) {
			k_sleep(K_MSEC(RUN_LED_BLINK_INTERVAL<<2));
		}

		setUartPowerOnState(true);		
 		//err = sensor_sample_fetch(tempDev);
		err = sensor_sample_fetch_chan(tempDev,SENSOR_CHAN_AMBIENT_TEMP);
		if (err != 0) {
			LOG_DBG("sample_fetch() failed: %d\n", err);
			return err;
		}

		err = sensor_channel_get(tempDev, SENSOR_CHAN_AMBIENT_TEMP, &temp);
		if (err != 0) {
			LOG_DBG("channel_get() failed: %d\n", err);
			return err;
		}
		
		setUartPowerOnState(false);

		app_temperature_value = temp.val1<<16 | (temp.val2/10000);
		if(tmpTemp != app_temperature_value) {
			my_fbs_send_temperature_notify(app_temperature_value);
			tmpTemp = app_temperature_value;
			//dutyToBeUpdate=true;
			k_sem_take(&dutycycle_sem, K_NO_WAIT);
			dutyToBeUpdate = true;
			k_sem_give(&dutycycle_sem);			
		}

		// the temperature acquisition 
		counterLoop = 8;
		while(counterLoop>0) {
			//LPP TODO send notificaton also in case a setPwmDuration is called
			if(dutyToBeUpdate) {
				setPwmDuration();
				my_fbs_send_dutycycle_notify(app_getDutyCycle_cb());
				//dutyToBeUpdate = false;
				k_sem_take(&dutycycle_sem, K_FOREVER);
				dutyToBeUpdate = false;
				k_sem_give(&dutycycle_sem);
			}
			if(app_leds_state)
				gpio_pin_set_dt(&led0_spec, (++blink_status) % 2);
			k_sleep(K_MSEC(RUN_LED_BLINK_INTERVAL));
			counterLoop--;
		}
	}
}

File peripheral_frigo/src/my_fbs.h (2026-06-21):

/*
 * Copyright (c) 2018 Nordic Semiconductor ASA
 *
 * SPDX-License-Identifier: LicenseRef-Nordic-5-Clause
 */

#ifndef BT_LBS_H_
#define BT_LBS_H_

/**@file
 * @defgroup bt_lbs LED Button Service API
 * @{
 * @brief API for the LED Button Service (LBS).
 */

#ifdef __cplusplus
extern "C" {
#endif

#include <zephyr/types.h>
#undef __CDT_PARSER__
#undef __JETBRAINS_IDE__
/** @brief FBS Service UUID. */

#define BT_UUID_FBS_VAL BT_UUID_128_ENCODE(0x9b046cc7, 0xdec2, 0x438f, 0xbde5, 0xb093f4b5511c)

/* Assign a UUID to the TEMPERATURE characteristic */
/** @brief TEMPERATURE Characteristic UUID. */
#define BT_UUID_FBS_TEMPERATURE_VAL                                                                   \
	BT_UUID_128_ENCODE(0x9b046cc8, 0xdec2, 0x438f, 0xbde5, 0xb093f4b5511c)

/* Assign a UUID to the DUTYCYCLE characteristic */
/** @brief DUTYCYCLE Characteristic UUID. */
#define BT_UUID_FBS_DUTYCYCLE_VAL                                                                   \
	BT_UUID_128_ENCODE(0x9b046cc9, 0xdec2, 0x438f, 0xbde5, 0xb093f4b5511c)

/** @brief EnableFan2 Characteristic UUID. */
#define BT_UUID_FBS_ENABLE_FAN2_VAL                                                                   \
	BT_UUID_128_ENCODE(0x9b046cca, 0xdec2, 0x438f, 0xbde5, 0xb093f4b5511c)

/** @brief Set Temperature Threshold Characteristic UUID. */
#define BT_UUID_FBS_TEMP_THRESHOLD_VAL                                                                   \
	BT_UUID_128_ENCODE(0x9b046ccb, 0xdec2, 0x438f, 0xbde5, 0xb093f4b5511c)

/** @brief Set PowerOn Characteristic UUID. */
#define BT_UUID_FBS_POWER_ON_VAL                                                                   \
	BT_UUID_128_ENCODE(0x9b046ccc, 0xdec2, 0x438f, 0xbde5, 0xb093f4b5511c)

#define BT_UUID_FBS_LEDS_ON_VAL                                                                   \
	BT_UUID_128_ENCODE(0x9b046ccd, 0xdec2, 0x438f, 0xbde5, 0xb093f4b5511c)

#define BT_UUID_FBS_PSW_SET_VAL                                                                   \
	BT_UUID_128_ENCODE(0x9b046cce, 0xdec2, 0x438f, 0xbde5, 0xb093f4b5511c)

#define BT_UUID_FBS BT_UUID_DECLARE_128(BT_UUID_FBS_VAL)
/* Convert the array to a generic UUID */
#define BT_UUID_FBS_TEMPERATURE BT_UUID_DECLARE_128(BT_UUID_FBS_TEMPERATURE_VAL)
#define BT_UUID_FBS_DUTYCYCLE BT_UUID_DECLARE_128(BT_UUID_FBS_DUTYCYCLE_VAL)
#define BT_UUID_FBS_ENABLE_FAN2 BT_UUID_DECLARE_128(BT_UUID_FBS_ENABLE_FAN2_VAL)
#define BT_UUID_FBS_TEMP_THR BT_UUID_DECLARE_128(BT_UUID_FBS_TEMP_THRESHOLD_VAL)
#define BT_UUID_FBS_POWER_ON BT_UUID_DECLARE_128(BT_UUID_FBS_POWER_ON_VAL)
#define BT_UUID_FBS_LEDS_ON BT_UUID_DECLARE_128(BT_UUID_FBS_LEDS_ON_VAL)
#define BT_UUID_FBS_PSW_SET BT_UUID_DECLARE_128(BT_UUID_FBS_PSW_SET_VAL)
/** @brief Callback type for when an TEMPERATURE read request is received. */
typedef int32_t (*get_Temperature_cb_t)(void);

/** @brief Callback type for when an DUTYCYCLE read request is received. */
typedef uint32_t (*get_DutyCycle_cb_t)(void);

/** @brief Callback type for when an DUTYCYCLE state change is received. */
typedef void (*set_DutyCycle_cb_t)(const uint32_t dutycycle_value);

/** @brief Callback type for when an FAN2 read request is received. */
typedef uint8_t (*get_Fan2_cb_t)(void);

/** @brief Callback type for when an FAN2 state change is received. */
typedef void (*set_Fan2_cb_t)(const uint8_t fan2_state);

/** @brief Callback type for when an TEMPERATURE CHANGE state change is received. */
typedef uint32_t (*get_threshold_cb_t)(void);

/** @brief Callback type for when an TEMPERATURE CHANGE state change is received. */
typedef void (*set_threshold_cb_t)(const uint32_t threshold_value);

/** @brief Callback type for when an POWERON state change is received. */
typedef bool (*get_poweron_cb_t)(void);

/** @brief Callback type for when an POWERON state change is received. */
typedef void (*set_poweron_cb_t)(const bool power_state);

/** @brief Callback type for when an LEDSON state change is received. */
typedef bool (*get_ledson_cb_t)(void);

/** @brief Callback type for when an LEDSON state change is received. */
typedef void (*set_ledson_cb_t)(const bool leds_state);

/** @brief Callback type for when an PSW state change is received. */
typedef void (*set_psw_cb_t)(const uint32_t psw_val);
/** @brief Callback struct used by the LBS Service. */
struct my_fbs_cb {
	get_Temperature_cb_t temperature_cb; 
	get_DutyCycle_cb_t getDuty_cb;
	set_DutyCycle_cb_t setDuty_cb;
	get_Fan2_cb_t getFan2_cb;
	set_Fan2_cb_t setFan2_cb;
	get_threshold_cb_t getThreshold_cb;
	set_threshold_cb_t setThreshold_cb;
	get_poweron_cb_t getPowerOn_cb;
	set_poweron_cb_t setPowerOn_cb;
	get_ledson_cb_t getLedsOn_cb;
	set_ledson_cb_t setLedsOn_cb;
	set_psw_cb_t setPsw_cb;
};

/** @brief Initialize the LBS Service.
 *
 * This function registers application callback functions with the My LBS
 * Service
 *
 * @param[in] callbacks Struct containing pointers to callback functions
 *			used by the service. This pointer can be NULL
 *			if no callback functions are defined.
 *
 *
 * @retval 0 If the operation was successful.
 *           Otherwise, a (negative) error code is returned.
 */
int my_fbs_init(struct my_fbs_cb *callbacks);


/** @brief Send the sensor value as notification.
 *
 * This function sends an uint32_t  value, typically the value
 * of a simulated sensor to all connected peers.
 *
 * @param[in] temperature_value The value of the simulated sensor.
 *
 * @retval 0 If the operation was successful.
 *           Otherwise, a (negative) error code is returned.
 */
int my_fbs_send_temperature_notify(uint32_t temperature_value);

/** @brief Send the sensor value as notification.
 *
 * This function sends an uint32_t  value, typically the value
 * of a simulated sensor to all connected peers.
 *
 * @param[in] dutycycle_value The value of the simulated sensor.
 *
 * @retval 0 If the operation was successful.
 *           Otherwise, a (negative) error code is returned.
 */
int my_fbs_send_dutycycle_notify(uint32_t dutycycle_value);

#ifdef __cplusplus
}
#endif

/**
 * @}
 */

#endif /* BT_LBS_H_ */

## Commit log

2026-06-21 Prima versione del progetto
    Progetto basato sul chip bluethooth nrf52832 della nordic semicondutor consente il controllo automatico della ventilazione del vano esterno del frigo trivalente del camper.
    Al fine di avere un efficienza migliore nel periodo estivo in cui le alte temperature ambientali non permettono il corretto scambio termico della serpentina.
    [pwm-servo.yaml]
2026-06-22 aggiornato il readme di progetto
2026-06-22 Libreria simboli kicad 9
2026-06-22 Aggiunta libreria footprint Kicad 9
2026-06-22 Aggiunto progetto Kicad 9
    [Ventole_Nrf52-B_Cu.gbr, Ventole_Nrf52-B_Mask.gbr, Ventole_Nrf52-B_Paste.gbr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]
2026-06-23 Create torem
    creazione cartella immagini pcb
2026-06-23 aggiunte immagini pcb
2026-07-05 fix dutycycle per seconda fan predisposto per DFU/FOTA
    [main.c]
